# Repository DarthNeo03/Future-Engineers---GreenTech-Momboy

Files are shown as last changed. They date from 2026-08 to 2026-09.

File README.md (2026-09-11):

# GreenTech Momboy — WRO 2026 Future Engineers

Engineering documentation for our self-driving car: a 200 × 180 × 150 mm
printed chassis, one drive motor through a mechanical differential, Ackermann
steering, and a single USB camera that we turned into a distance sensor.

**Team GreenTech Momboy — Venezuela.** Two students, one coach, seventeen
chassis revisions and about four months of evenings.

| | |
|---|---|
| Category | Future Engineers |
| Season | WRO 2026 |
| Country | Venezuela |
| Vehicle | 200 mm × 180 mm × 150 mm — limit is 300 × 200 mm and 300 mm tall |
| Controllers | Raspberry Pi 5 (8 GB) + ESP32 |
| Perception | 1 USB camera, 1 gyroscope, 1 floor colour sensor |
| Software | Python 3.11 + OpenCV on the Pi, Arduino C++ on the ESP32 |
| Status | Both challenges running; parking manoeuvre in progress |

---

## The car

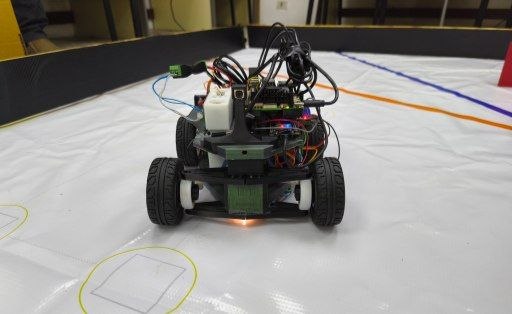
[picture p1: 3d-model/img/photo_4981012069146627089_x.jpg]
Front view


*Fig. 1 — Front view. Front axle, steering geometry at ride height, and the
status LED on the electronics deck.*

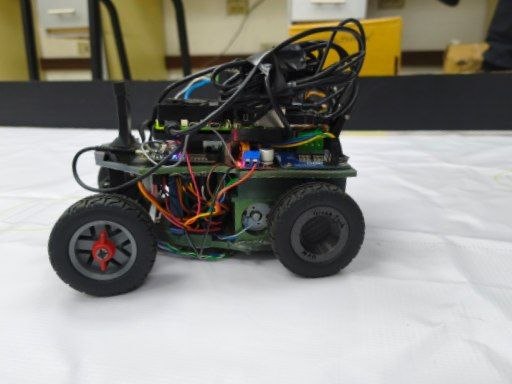
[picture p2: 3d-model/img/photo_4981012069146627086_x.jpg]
Side view


*Fig. 2 — Side profile. Wheelbase, motor/gearbox housing in the lower
chassis, and the wiring harness routed along the middle deck.*

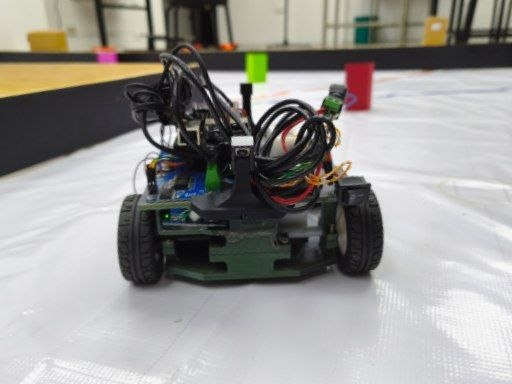
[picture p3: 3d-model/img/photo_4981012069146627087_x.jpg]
Rear view


*Fig. 3 — Rear view. Camera mast rising from the electronics deck, between
the rear wheels and the differential housing.*

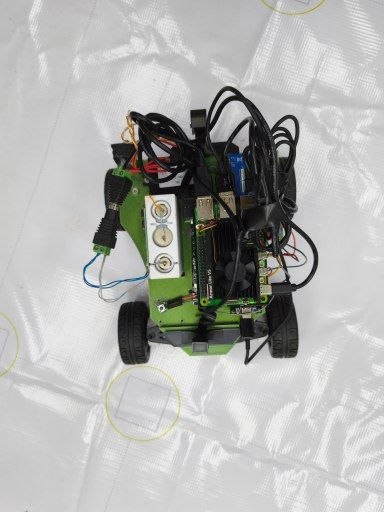
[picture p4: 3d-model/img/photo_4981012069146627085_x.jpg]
Top view


*Fig. 4 — Top view. Raspberry Pi 5 and wiring harness on the upper deck,
showing the wheel track and overall footprint.*

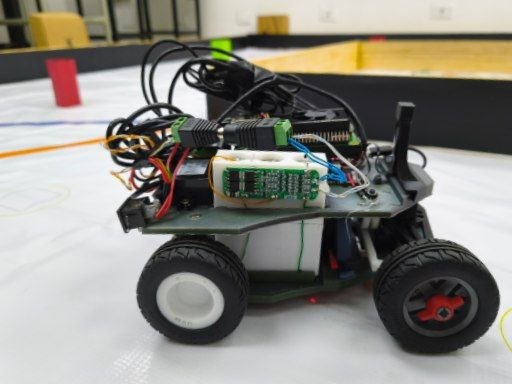
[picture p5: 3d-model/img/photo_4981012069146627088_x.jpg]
Front-quarter view


*Fig. 5 — Front, ¾ view. Front suspension links and the sensor mounts ahead
of the steering rack.*

---

## Contents

- [The car](#the-car)
- [Repository map](#repository-map)
- [The team](#the-team)
- [The vehicle](#the-vehicle-mobility-management)
- [Power and sensors](#power-and-sensors)
- [Software](#software-architecture)
- [Obstacle strategy](#obstacle-strategy)
- [Why we chose what we chose](#why-we-chose-what-we-chose)
- [Testing and reproducing our work](#testing-and-reproducing-our-work)
- [Rules compliance](#rules-compliance)

## Repository map

| Folder | What is in it |
|---|---|
| [`main/`](main/) | The car we race. Pilot program (Pi) + ESP32 firmware. Both challenges, selected by profile |
| [`fallback/`](fallback/) | The previous system, still runnable: reconizer (Pi) + the same firmware |
| [`schemes/`](schemes/) | Wiring diagram, system block diagram, pinout, power budget |
| [`3d-model/`](3d-model/) | Printed parts (STL) and the sliced projects with the settings we used |
| [`images/`](images/) | Team and vehicle photos, build photos, and the frames the car itself recorded |
| [`journal/`](journal/) | The engineering journal, the test logs, and the previous prototype |
| [`video/`](video/) | Links to the driving videos, one per challenge |

The two code folders are each complete and runnable on their own: `main/` is the
car we race today, `fallback/` is the system that came before it. Keeping both
means we can go back to a known-good program in the pits by changing which
`main.py` we launch, instead of reverse-engineering a git revert under pressure.

There is no separate folder per challenge. It is one program that runs both
rounds, and the round is chosen by which calibration profile is loaded — the
Obstacle Challenge simply switches obstacle handling on. Splitting it into two
copies would have meant fixing every bug twice.

Printed parts in [`3d-model/Documentación 3D/`](3d-model/Documentación%203D/)
are grouped by subassembly — full detail (screenshots, `.3mf` per part) in
[`3d-model/README.md`](3d-model/README.md#parts):

| Group | Function | Individual parts |
|---|---|---|
| [`A-Arm`](3d-model/Documentación%203D/A-Arm/) | Front suspension links | Lower A-Arm Left, Lower A-Arm Right, Upper A-Arm (2pcs) |
| [`Battery`](3d-model/Documentación%203D/Battery/) | Battery case and cell retention | Case (Lower/Upper 3S1P), Fittings (Cylinder ×4, Rectangle ×4) |
| [`Camera`](3d-model/Documentación%203D/Camera/) | Camera mast and mount | CameraMount, Camera Support Mount, LowerCameraMount, Pin |
| [`Chassis`](3d-model/Documentación%203D/Chassis/) | Structural core: motor mount, gear supports, steering rack housing, electronics deck | Lower, Middle, Upper Chassis, MotorChassis |
| [`Diferrential`](3d-model/Documentación%203D/Diferrential/) | Mechanical differential and drive gear train, rear axle | Crown Gear, Differential Case Cover, Left/Right Axle Support, MotorGear, PlanetGear (2pcs) + Axle, RearGearAndRing Left/Right |
| [`RaspberryPi5Mount`](3d-model/Documentación%203D/RaspberryPi5Mount/) | Raspberry Pi 5 mounting plate | RaspberryPi5Mount |
| [`Steering`](3d-model/Documentación%203D/Steering/) | Rack-and-pinion steering, Ackermann geometry | FrontRing (2pcs), FrontWasher, Servo Bracket, Steering Knuckle Left/Right, SteeringRack, SteeringServoGear, SteeringStop |

## The team

| | |
|---|---|
| **José Simón García Castellanos** | Obstacle challenge: pillar detection, avoidance geometry, the overtaking commitment |
| **Cristian José Rangel** | Open challenge: wall following, corner detection and counting, the CAD of the chassis |
| **Tutor / Coach** | **Msc. Edgardo Paolini** |

Both of us worked on every prototype, early and late. We split by *challenge*
rather than by layer on purpose: each of us owns a full vertical slice — camera
to wheels — for one round, which means either of us can debug an entire round
end to end without waiting for the other. The branches are shared, the debug
panel shows the same telemetry to both, and the merges are where we review each
other's work.

Our coach did not build or program the car — the rules are explicit about that,
and so are we. What our coach did was make sure a track existed to practise on,
ask "how do you know?" every single time we claimed something worked, and make
us stop and write things down at the exact moments we would rather have kept
hacking. Most of the failure analysis in this repository exists because somebody
kept asking that question.

## The vehicle (mobility management)

| | |
|---|---|
| Size | ≈ 200 mm long, 180 mm wide, 150 mm tall |
| Wheelbase | ≈ 150 mm |
| Wheels | Ø 65.2 mm |
| Drive | 1 DC motor, 500 rpm, 2:1 gearing, rear axle with a mechanical differential |
| Steering | Servo MG996R on a rack and pinion, Ackermann geometry, ≈26° at full lock |
| Top speed | ≈ 850 mm/s at full PWM; we cruise at about a fifth of that |
| Turning radius | ≈ 310 mm |
| Chassis | Printed PLA, seventeen revisions |
| Weight | 1150 g — limit is 1500 g |

### Speed and torque

The first motor we looked at ran at 1000 rpm. On a 3 × 3 m track with corners
every 3 metres, that is not fast, it is unusable: at that speed the car crosses
a floor line between two samples of the colour sensor, and the control loop
spends every corner recovering instead of driving. We went to a 500 rpm motor
with 2:1 gearing to the axle, which puts about 850 mm/s at the wheel with the
PWM at maximum — and in practice we run cruise at 55 out of 255, roughly
180 mm/s, because on this track reliability scores more points than speed.

Gearing down also gives us the torque to start smoothly from a stop, which
matters at the very beginning of the round: the parking bay start leaves no room
for a wheel-spinning launch.

### One motor, one steering actuator

The rules require exactly this, and they disqualify a differential-wheeled base.
So: one motor drives both rear wheels through a **mechanical differential**, and
one servo steers the front wheels through a rack and pinion with Ackermann
geometry. Nothing about direction is done by driving one side faster than the
other.

Ackermann steering shapes the software more than anything else on the car: the
rear wheel cuts inside the front one, so the car cannot return to the middle of
the lane the instant it has passed a pillar. That single geometric fact is where
the "overtaking commitment" in the obstacle code comes from.

### Why the chassis got smaller

We designed the first chassis around the components, and it was too long. The
compact chassis (revision XVII) came out of a list of things that were costing
us points on the track, and every item on that list was geometry:

- **The parking bay is 20 cm wide and 1.5 × the length of the robot.** A shorter
  car needs a shorter bay and can place itself less precisely. That is the
  cheapest improvement to the parking manoeuvre available, and it happens before
  any code runs.
- **The narrow track configuration is 600 mm wide.** With a 150 mm wheelbase and
  ~26° of lock we turn inside ~310 mm of radius, which fits.
- **The tail used to knock over the pillar we had just passed.** A shorter,
  narrower car sweeps a smaller area on the way out of an avoidance.
- **The camera stopped moving.** Every distance the software computes comes from
  two numbers, camera height (125 mm) and tilt (7.5°). On the old chassis the
  mast flexed, so those numbers were not constant, so no calibration held. On
  this one the mast is part of the structure.
- **Smaller parts print faster and fail less**, which decides how quickly you
  recover when something snaps two days before a test.

The full story, with dates, is in [`journal/engineering-journal.md`](journal/engineering-journal.md).

## Power and sensors

System block diagram

Full detail: [`schemes/`](schemes/) — [pinout](schemes/pinout.md),
[power budget](schemes/power-budget.md),
[wiring diagram](schemes/wiring-diagram.svg).

### Bill of materials

| Part | What it does | Where it connects |
|---|---|---|
| Raspberry Pi 5, 8 GB | Vision and decisions | USB camera, USB to the ESP32 |
| ESP32 | Hardware control and failsafe | Pi over USB serial (or GPIO 16/17) |
| Camera WN-L1812.K56R (IMX179) | The only sensor that sees the track | USB 2.0, MJPG, 30 fps |
| MPU-6050 | Yaw: heading on straights, closing the 90° turns | I2C 0x68 + INT on GPIO 18 |
| TCS34725 | Floor colour: the orange and blue corner lines | I2C 0x29 + INT on GPIO 19 |
| IBT-2 (BTS7960) | H-bridge for the drive motor | GPIO 25/26/27/33, PWM 20 kHz |
| Servo MG996R | Steering | GPIO 32, 50 Hz, 500–2400 µs |
| DC motor 500 rpm | Drive | Through 2:1 gearing to the rear axle |
| Battery pack | **TODO (team): chemistry, cells, capacity** | Main switch → H-bridge and regulator |

### Three sensors, and why not more

**The camera is the distance sensor.** With the lens at a known height and a
known tilt, every pixel on the floor maps to a millimetre distance. That gives
us a distance profile across the whole width of the image — a poor man's lidar —
instead of a single point. All the thresholds in the code (`turn below X mm`,
`stop below Y mm`) are physical distances, which is why the same calibration
works on the 1000 mm track and on the 600 mm one.

**We tried distance sensors and dropped them.** A single-point sensor cannot
tell a wall from a pillar, and it adds a rail, a cable and a failure mode for
information the camera already produces across the whole frame.

**The gyroscope earns its place** because an angle measured *from the car* is
useless for telling one wall from another — it changes with how crooked the car
is. The angle relative to the *track* is what matters, and converting between
the two needs exactly one number: how far the car has drifted from the heading
of the straight. That is the gyro. With it, one wall is enough to know whether
it is the wall of your lane or the far wall of the corner, even with the car
crossed at 45°.

**The colour sensor earns its place** because it is the only physical fact the
car gets. Everything else is inference from an image; the orange or blue line
passing under the car *happened*.

### Handling sensors that are not there

Both INT lines are optional: if they are not wired, the firmware detects it and
falls back to polling. On a competition weekend a broken jumper should cost
precision, not the round. The panel shows, sensor by sensor, what was detected.

That behaviour came from a real failure: the ESP32 used to probe the I2C bus
immediately after `Wire.begin()`, before the sensors woke up and while the motor
start-up pulled the rail down, and then declared both absent for the rest of the
run. Wait 250 ms, retry every 3 s, and give the humans a manual retry button.

### The start button, and stopping without the panel

The rules want the round to begin with a single action on a robot already
sitting on the track: no keyboard, no screen, no cable, nothing wireless. So
there is **one push button** on GPIO 13 — two wires and the internal pull-up,
no resistor — and it works like the start/stop of a stopwatch:

| Press it | With the car | What happens |
|---|---|---|
| once | stopped | arms and starts the round |
| again | running | disarms and stops |

Two details we argued about and are glad we got right:

- **It travels as a level, not as a counter.** A floor line is crossed in 40 ms
  and has to be latched and counted or it is lost; a finger holds a button for
  100–300 ms, which is four to twelve sensor frames. And a counter would store
  presses: a serial glitch with an undelivered press could start the car *by
  itself* on reconnect. With a level, what is lost is simply not executed —
  "nothing happens" is the good failure to have in front of a judge.
- **The emergency cut happens in the ESP32, not in the Pi.** With one button the
  ESP32 cannot know what a press means — except in the case that matters: if the
  car is *armed*, a press can only mean stop. Nobody presses to arm a car that is
  already moving. So it latches a local cut and the motor is dead on the next
  10 ms tick, without the round trip over serial and even if the Pi is hung
  shouting "forward".

A blue LED on GPIO 2 shows the state, so we can tell from outside the track
whether the car is armed, disarmed, or cut by the button.

There is also a daemon (`piloto.sh`) that runs the pilot with no web panel, so
in competition nothing on the car needs a network at all.

### Calibration, and the rule that shapes it

The rules do not let us calibrate after technical inspection, so everything is
calibrated before the car is handed in, and everything calibratable is saved as
a **profile** — up to twenty per challenge line, in three separate lines (Open
Challenge, obstacle avoidance, obstacles + parking) so that tuning one round can
never damage another round's working calibration.

Two habits that we learned the expensive way: freeze exposure and white balance
*before* calibrating colour, and never let the floor burn out — with white at
V=244 the floor lines drop to a saturation of 15–36 and no HSV threshold on
earth separates them from the floor.

## Software architecture

```
camera  →  geometry (px → mm)  →  wall profile ─┐
                                 lines ─────────┤→  navigation (state machine)  →  link  →  ESP32  →  motor + servo
                                 pillars ───────┘         ↑
                                                    race director (3 laps, stop in the finish section)
```

On the Pi (Python 3.11, OpenCV, NumPy — no ROS, no neural network):

| Module | Job |
|---|---|
| `geometria.py` | Pixels to millimetres on the floor; the horizon; the corridor the wheels will actually pass through |
| `muro.py` | Where the floor stops being floor; straight lines fitted in mm; inner and outer corners |
| `vision.py` | HSV masks and object detection: red and green pillars, orange and blue lines |
| `lineas.py` | Direction of the round, corner opening and closing, lap count |
| `navegacion.py` | The state machine: STRAIGHT, PRE-TURN, TURN 90, TWO-STAGE TURN, COLOUR TURN, ESCAPE |
| `obstaculos.py` | Which side to pass a pillar on, and committing to it |
| `carrera.py` | The race: three laps, twelve corners, stop inside the finish section, three-minute cap |
| `servidor.py` | The debug panel — bench and practice only |

On the ESP32 (Arduino C++, FreeRTOS, no external libraries): a receive task, a
sensor task woken by the sensors' own interrupts, a control task on a 10 ms
tick, a telemetry task, and a watchdog. No Wi-Fi is compiled in at all.

### The state machine, and the two bugs that shaped it

**Corners are entered on a physical fact.** The trigger we trust is the floor
line under the car, not the corridor closing in the image. A corner **opens**
with its first line and waits for the second to **close** it; the second can
never open a new one. With four corners in a row losing the blue line entirely,
the count still comes out at four.

**Once inside a corner, the turn is committed.** This is the fix for the corner
loop: when the inner wall ends it leaves a huge gap of white floor, and to any
free-space navigator that gap *is* the road. The car used to drive into it, see
another gap from its new position, and never come out — in one recorded capture
the corridor measured 1064 mm of clear road at precisely the moment the car had
to turn. So during the turn the camera cannot redirect the car; the turn ends on
the gyro angle or on a timeout, never because a tempting gap appeared. Safety
still overrides everything.

**The heading is re-anchored to the straight that exists.** The subtlest bug we
found: if the colour sensor missed a line, the car took the corner physically —
on white space alone — while the code still believed it was on the previous
straight, so the gyro pulled it back towards a straight that no longer existed
and into the wall. Now, if the car has held a corner-sized angle for long enough
*in the direction of the round*, it adopts the new straight.

**Reverse is special.** The only manoeuvres that reverse are the safety escape
and the two-stage turn — and the two-stage turn only runs on a corner confirmed
by a real pair of floor lines, because reversing in the middle of a straight
because the vision imagined a corner is how you hit whatever is behind you.

## Obstacle strategy

Red pillars are passed on their right, green on their left, and getting it wrong
ends the round. So the side is decided by the **colour** and is never
negotiable: only the distance is clipped to the free gap. If the gap is too
tight for a comfortable margin the car squeezes to the physical minimum (half a
car plus half a pillar); if not even that fits, it says so on screen and the
wall avoidance takes over.

Left and right are the *vehicle's*, so nothing needs flipping when the round
runs the other way. And because the cost of being wrong is the whole round, the
overlay draws a green arrow to the pass point and writes "red → pass on its
right", so we verify it with the car standing still.

Three failures worth reading, all fixed and all documented in
[`main/README.md`](main/README.md):

1. Steering saturating as the car closed on a pillar (96 % of lock at 600 mm,
   100 % at 400 mm) — fixed with a minimum look-ahead, a ceiling on what
   avoidance can ask for, and a slew-rate limit.
2. The rear wheel sweeping the pillar away once it left the camera's view —
   fixed with an overtaking commitment computed from real speed and car length.
3. A pillar against the inner wall driving the car into the corner — fixed by
   fading the pillar's authority as the corridor narrows, and by aiming at the
   middle of the gap when the gap is narrower than the car.

Pillars seen **behind** the floor lines belong to the next section and are
filtered out until the car enters the corner zone; reacting to them early drags
the car onto the inner corner exactly when it should be setting up to turn.

## Why we chose what we chose

| Decision | Alternative | Why |
|---|---|---|
| Raspberry Pi 5 + ESP32 | One controller doing everything | The vision loop used to stall the control loop. Now the control tick never misses, and if the Pi dies the ESP32 stops the car after 300 ms |
| ESP32 with no Wi-Fi compiled in | Wi-Fi for convenience | Two things that can give orders is one too many — and the rules forbid wireless while the vehicle runs |
| Classical computer vision (HSV + geometry) | A neural network | It runs at 30 fps on a CPU, it is deterministic, we can re-calibrate it in fifteen minutes at the venue, and when it fails we can point at the reason |
| Camera as the distance sensor | Lidar / time-of-flight sensors | Distance across the whole frame instead of one point, and one fewer thing to break. A single-point sensor cannot tell a wall from a pillar |
| Gyroscope kept | Camera only | Distinguishing "the wall of my lane" from "the far wall of the corner" needs the angle relative to the *track*, and only the gyro provides the conversion |
| Colour sensor kept | Detecting the corner lines with the camera only | The camera sees the line before it arrives; the sensor knows it *passed*. We use both, and the physical one is the one that counts corners |
| One motor + mechanical differential | Two motors, one per side | The rules disqualify a differential-wheeled base. Also, one motor cannot drift out of sync with itself |
| Profiles, everything tunable live | Recompiling to change a threshold | Nobody recompiles calmly at a competition |

## Testing and reproducing our work

```bash
git clone https://github.com/DarthNeo03/Future-Engineers---GreenTech-Momboy.git
cd Future-Engineers---GreenTech-Momboy/main/raspberry-pi

python3 -m venv .venv && source .venv/bin/activate
pip install -r requirements.txt      # opencv-python, numpy, pyserial

python3 tools/selftest.py            # 323 checks — no camera, no car, no ESP32
python3 main.py --simulado           # run the whole pilot on a laptop
python3 main.py --imagen ../../images/test-captures/frames/...   # replay a real frame
python3 main.py                      # the real thing: camera + ESP32 + panel
```

The ESP32 side: open `firmware/esp32/esp32_carro.ino` in the Arduino IDE (all
five files in the same folder) and upload — no external libraries. Upload new
firmware **before** running `main.py`.

Three things make this project reproducible, and they were worth more to us than
any single algorithm:

- **323 checks that run on any laptop.** Everything that can break hardware or
  count wrong lives in pure Python or pure C++ and is tested without the car.
  There is one car and two of us; whoever does not have it can still work.
- **The car records what it sees.** The frame sequences in
  [`images/test-captures/`](images/test-captures/) and the run logs in
  [`journal/test-logs/`](journal/test-logs/) are from real sessions, and any of
  them can be replayed offline. Every fix in September was accepted because a
  recorded run improved, not because the fix sounded right.
- **A synthetic scene in the self-test** reproduces the shiny-wall failure: the
  old wall-detection method fails on it and the new one does not, so the bug can
  never come back unnoticed.

## Rules compliance

| Requirement (WRO 2026 Future Engineers) | Us |
|---|---|
| Max 300 × 200 mm, 300 mm tall | 200 × 180 × 150 mm |
| Max 1500 g | 1150 g |
| Max two drive motors, connected to the axle through gearing | One motor, 2:1 gearing, mechanical differential |
| One steering actuator | MG996R on a rack and pinion |
| Differential-wheeled base disqualified | Ackermann steering; no independent side drive |
| No radio, Bluetooth or Wi-Fi while running | No Wi-Fi in the firmware; the Pi's panel and access point are shut down for the round |
| One switch, one start button | Main switch on the battery rail, and one push button on GPIO 13: press it once and the round starts, press it again and the car stops |
| Wired connections only between components | USB and jumper wires |
| No calibration after technical inspection | Everything is calibrated beforehand and saved as profiles |
| Repository public, and public for 12 months after the event | Public; will stay up |
| Three commits at the required deadlines | Our history runs from 7 May, with work committed continuously |
| README of at least 5000 characters | This one |
| Video of at least 30 s per challenge | [Open Challenge](https://youtu.be/Z215ovmq5Jg) (0:40) and [Obstacle Challenge](https://youtube.com/shorts/VIz5sVFtg74) (1:38) — also listed in [`video/video.md`](video/video.md) |
| The team builds and codes the robot, not the coach | Two students wrote every line and printed every part |

## License

See [`LICENSE`](LICENSE). The engineering notes inside
`main/raspberry-pi/README.md` and
`journal/prototypes/CONTEXTO-reconizer.md` are in Spanish, the language we work
in; everything a judge needs is in English here.

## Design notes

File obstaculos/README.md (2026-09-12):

# Sistema de control — Reto de Obstáculos

Pila completa y autocontenida para el **Desafío de Obstáculos** de WRO 2026
Future Engineers. Raspberry Pi 5 (visión y decisiones) + ESP32 (hardware y
failsafe), unidos por serial a 115200 8N1.

La **[bitácora](BITACORA.md)** cuenta cómo llegó a ser así: los nueve fallos
que aparecieron, cómo se aisló cada uno y qué queda pendiente —incluido lo que
puede romper hardware. Este README explica cómo funciona; la bitácora, por qué.

No hay nada de estacionamiento en este código. Los delimitadores magenta del
cajón sí aparecen, pero **como muro intocable**, nunca como objetivo: la regla
9.25.7 termina la ronda en el instante en que el vehículo los toca.

---

## Mapa de conexiones

| Función | Pin ESP32 | Detalle |
|---|---|---|
| Tracción RPWM | GPIO 25 | IBT-2 (BTS7960), PWM 20 kHz / 8 bits |
| Tracción LPWM | GPIO 26 | idem |
| Tracción R_EN | GPIO 27 | habilitación; en BAJO = puente en alta impedancia |
| Tracción L_EN | GPIO 33 | idem |
| Dirección | GPIO 32 | servo MG996R, 50 Hz, 500–2400 µs, 16 bits |
| I2C SDA | GPIO 21 | bus a 400 kHz |
| I2C SCL | GPIO 22 | |
| MPU-6050 | 0x68 | INT (data ready) → GPIO 18, push-pull, activo ALTO |
| TCS34725 | 0x29 | INT (umbral de claro) → GPIO 19, open-drain, activo BAJO |
| Botón de inicio | GPIO 13 | a GND, pull-up interno |
| LED de estado | GPIO 2 | azul de a bordo |
| Serial2 RX2 | GPIO 16 | ← TX de la Pi |
| Serial2 TX2 | GPIO 17 | → RX de la Pi |
| Cámara | — | WN-L1812.K56R (IMX179) por USB 2.0 a la Pi, MJPG 640×480 @30 |

Las dos patas INT son **opcionales**: el firmware detecta solo si están
cableadas y, si no, sigue por sondeo. Con ellas el rumbo se integra con el `dt`
real del sensor y los cruces de línea llevan marca de tiempo del ISR.

---

## Reparto de responsabilidades

```
Raspberry Pi 5                             ESP32
──────────────                             ─────
cámara → visión → geometría                tareaRx        valida CRC, publica
        ↓                                  tareaSensores  MPU + TCS por I2C
  carril  +  señales   (por separado)      tareaControl   100 Hz, rampas, HW
        ↓                                  tareaVigilante corta si algo calla
      mezcla → FSM → Orden
        ↓
   hilo TX a 50 Hz  ─────── serial ──────► failsafe a 300 ms
```

Regla de diseño: **la Pi piensa, el ESP32 obedece y desconfía.** Si la Pi se
cuelga, el ESP32 corta la tracción él solo a los 300 ms. Si la tarea de control
del ESP32 se cuelga, el vigilante baja los enables a los 200 ms.

El motor necesita **dos llaves**: el botón físico (`armadoLocal`, que vive en el
ESP32) y la bandera `F_ARMADO` de la Pi. Ninguna de las dos basta por sí sola.

---

## Estructura

```
firmware/esp32/esp32_obstaculos/     (la carpeta debe llamarse como el .ino:
  esp32_obstaculos.ino   pines, PWM, tareas FreeRTOS, failsafe   lo exige el IDE)
  protocolo.h            trama binaria  ← gemelo de src/protocolo.py
  seguridad.h            topes del servo, rampas, protección de inversión
  sensores_i2c.h         MPU-6050 y TCS34725 a registro
  lineas.h               clasificador naranja/azul del piso
  panel.h                botón antirrebote + patrones del LED

raspberry-pi/
  main.py                punto de entrada
  config/pista.json      todo lo ajustable
  src/protocolo.py       trama binaria  ← gemelo de protocolo.h
  src/enlace.py          serial: hilo RX + hilo TX a 50 Hz
  src/camara.py          captura MJPG en hilo, buffer de uno
  src/geometria.py       píxeles → milímetros sobre el suelo
  src/vision.py          segmentación HSV → escena en milímetros
  src/carril.py          mantenerse en la pista
  src/senales.py         rebasar los pilares por el lado que manda la regla
  src/vueltas.py         contar secciones y vueltas, y de qué lado se corre
  src/fsm.py             máquina de estados
  src/piloto.py          lazo principal
  src/panel.py           ventana de depuración (solo taller)
  tools/selftest.py      pruebas sin carro
```

---

## Puesta en marcha

**1. Firmware.** Arduino IDE con el core **ESP32 3.x** (la API `ledcAttach` /
`ledcWrite(pin, ...)` es de la 3.x; con la 2.x no compila). Abrir
`firmware/esp32/esp32_obstaculos/esp32_obstaculos.ino` y subir. No hace falta ninguna librería
externa: los dos sensores están escritos a registro sobre `Wire`.

**2. Pi.**

```bash
cd obstaculos/raspberry-pi && pip install -r requirements.txt
```

**3. Comprobar sin carro.**

```bash
python3 tools/selftest.py
```

**4. Rodar.**

```bash
python3 main.py
```

y pulsar el botón del carro cuando el juez diga «¡ya!».

En el taller: `--sin-motor` (pone el techo de PWM a 0, así ninguna rama del
código puede mover nada), `--ver` (ventana de depuración), `--puerto COM7`,
`--lineas` (monitor del sensor de color, empujando el carro a mano).

---

## Calibración, en el orden en que hay que hacerla

Cada paso supone que el anterior está bien. Saltarse el orden es la forma
habitual de perder una tarde persiguiendo un fallo que estaba dos pasos antes.

1. **Servo.** Con el carro levantado, comprobar que `centro` deja las ruedas
   rectas y que `izquierda`/`derecha` no hacen tope contra la cremallera. Los
   topes duros están en `seguridad.h` como constantes de compilación: el JSON
   solo puede estrechar ese rango, nunca ampliarlo.

2. **Geometría de la cámara.** El parámetro que de verdad importa para los
   pilares es **`fy_px`**: la distancia a una señal se deduce de su altura
   aparente, y eso solo depende de la focal. Resuélvelo poniendo un pilar a
   una distancia conocida.

   `inclinacion_deg` y `alto_cam_mm` son secundarios a propósito: solo afectan
   a la medida por base, que ahora únicamente corrobora. Un mástil torcido ya
   no hace desaparecer los pilares — antes sí, y por eso el carro los
   ignoraba. Si aun así quieres afinarlos, la ventana de `--ver` muestra las
   dos distancias juntas: cuando se separan mucho, vuelve a medir el mástil.

3. **Colores.** Con `--ver`, sobre el tapete de verdad y con la luz de verdad.
   Lo que importa no es que el pilar se vea entero: es que **nada más** se vea.

4. **`pwm_min_motor`.** Súbelo de 5 en 5 (arranca en 55) hasta que el carro
   arranque limpio desde parado sobre el tapete, y ni uno más. Es lo que evita
   que el motor zumbe sin moverse a bajo porcentaje.

5. **`mm_s_por_pct`.** Mandar 40 % durante 3 s en recta, medir la distancia,
   dividir. De este número dependen el odómetro y la duración del compromiso.

6. **`color_entrada_horario`.** Empujar el carro a mano por la pista en sentido
   horario y mirar qué color reporta el primer cruce. **No se adivina**: de
   esto depende que el sentido de la ronda se deduzca bien.

   De este único parámetro salen las dos respuestas: el color suelto da el
   sentido *provisional* en cuanto se pisa la primera línea, y el par
   ordenado (entrada + el otro color) lo *confirma* al completar la primera
   esquina. En `--ver`, la línea `sentido` dice cuál de las dos está mandando.

---

## Lo que este sistema no sabe hacer

Dicho antes de que lo descubra la pista:

- **No hay encoder en las ruedas.** El odómetro se integra del porcentaje de
  mando (`mm_s_por_pct`), con un error del 10–15 %. Basta para medir el tramo
  de recta hasta la meta, pero no serviría para navegar por estima. Por eso el
  detector de atasco mira **la imagen**, no la velocidad estimada: preguntarle
  al acelerador si el coche se mueve no sirve de nada cuando está clavado.
- **Un pilar cada vez.** Con dos pilares seguidos se resuelve el primero y el
  segundo se replantea después. Planificar los dos a la vez con una sola cámara
  sale peor de lo que parece. Lo que sí se hace es **verlo antes**: ver la
  sección siguiente de abajo.
- **El firmware no está compilado en este repositorio.** No hay compilador
  cruzado en la máquina donde se escribió: `protocolo.h`, `seguridad.h` y
  `lineas.h` son C++ puro a propósito y se pueden verificar con `g++` en un PC,
  pero el `.ino` hay que abrirlo en el IDE para confirmarlo.
- **Los rangos HSV del `pista.json` son un punto de partida**, no una
  calibración. Ninguna tabla de colores sobrevive a un pabellón nuevo.

---

## Qué pasa justo después de esquivar

Es el momento más delicado de la vuelta. El pilar ya no se ve —la cámara no
llega tan abajo— y el carro va apuntando hacia el lado por el que lo rebasa.

- **El seguidor de carril está callado a propósito.** Si opinara, tiraría del
  carro hacia el centro del carril y la rueda trasera barrería el pilar: con
  dirección Ackermann la cola corta por dentro.
- **Lo que se sostiene es el rumbo, no el volante.** Se congela el *yaw* del
  MPU del instante en que el pilar entró en zona ciega y un proporcional
  devuelve el carro a él. Un volante fijo no traza una recta, traza un arco:
  con el modelo Ackermann simplificado, congelarlo 0,8 s desviaba **537 mm**,
  más de medio carril, directo al muro.
- **Pero el compromiso no termina soltando el carro donde esté: lo devuelve
  alineado.** Pasada `salida_desde` (55 %) del compromiso el pilar ya quedó
  atrás, y el rumbo objetivo se lleva poco a poco del congelado al del pasillo
  libre que ve el carril. Sin esto, el carril recibía un carro cruzado y con el
  muro delante, que es de donde salía el volantazo siguiente.
- **Sin MPU se endereza, y rápido.** No hay rumbo que sostener, así que el
  volante se suelta en `soltar_sin_mpu_s` (0,35 s) de reloj y el resto del
  adelantamiento se hace recto. Antes se desvanecía a lo largo de *todo* el
  compromiso, o sea que se mantenía casi entero durante la primera mitad: eso
  es el arco, otra vez, y contra la pared. Aun así, revisa el I²C: recto es lo
  mejor que se puede hacer a ciegas, no es tan bueno como sostener el rumbo.
- **La guardia anti-muro sí sigue despierta** (`guardia_muro` en `carril.py`).
  No centra: se calla mientras haya sitio y solo empuja cuando la separación
  lateral baja de `guardia_muro_mm`. Su autoridad crece con el progreso del
  adelantamiento, porque al principio el pilar sigue al costado y al final ya
  quedó atrás.

### Y después del compromiso hay un estado propio: REINCORPORACION

Lo que sale de un rebase no es un carro en pista: es un carro descolocado
hacia un lado y apuntando al muro, así que su cámara ve el frente cerrado.
Devolverlo directamente a `PISTA` era el fallo que dejaba al carro girando
hacia el lado del esquive hasta clavarse en la pared, porque el seguidor de
carril leía ese frente cerrado como una esquina y hacía las dos cosas que no
tocaban a la vez: bajar el centrado al 25 % —el único término que aparta al
carro del muro— y empujar con `sesgo_curva` hacia el lado al que giran las
curvas de la ronda.

**Y va RECTA, no al centro.** Son cosas distintas, y confundirlas era la
desviación que seguía viéndose después de cada esquive: el seguidor de carril
no va recto, va al *centro*, así que a un carro que sale del rebase desplazado
le manda cruzar — y el carro hace una ese (se cruza, se pasa, vuelve). Aquí se
sostiene el **rumbo** con el yaw, igual que en el compromiso, y el rumbo bueno
ya lo dejó puesto el propio compromiso al reenfilar hacia el pasillo. Lo único
que se le suma es la guardia anti-muro: no centra, solo impide el golpe.
Recentrarse es cosa de la recta siguiente, con sitio y sin prisa. Sin MPU no
hay rumbo que sostener y manda el carril; se nota.

El piloto además le pasa al carril `tras_pilar=True`, y con eso:

| Qué se apaga | Por qué |
|---|---|
| el sesgo de curva | ese frente cerrado no es una esquina, es el muro al que se apunta |
| el aprendizaje del sentido | esos grados de rumbo no son de ninguna curva; si entraran en el promedio, el sentido "aprendido" sería el del último esquive |
| la rebaja del centrado | es lo único que saca al carro del muro |

Se sale a `PISTA` cuando el carro está **enfilado** y despegado del muro
(`reincorporado_deg`) o cuando se agota `reincorporacion_max_s`. Enfilado, no
centrado: exigir centrado mientras se va recto a propósito es pedir algo que
este estado no hace, y se saldría siempre por tiempo. Un pilar nuevo interrumpe el estado y manda a `SENAL`:
recolocarse no puede ser excusa para pasar de largo la señal siguiente.

Medido en el escenario de prueba (carro a 150 mm del muro derecho después de
rebasar por la derecha, ronda horaria): el volante pasa de **−12 %** —un
empujón simbólico, porque el sesgo de curva tiraba hacia el muro— a **−66 %**.

### Un muro de frente no es un muro al costado

Fallo de fondo que salió al montar un escenario de prueba con la geometría de
verdad, y que explica por qué la guardia anti-muro nunca salvaba al carro. La
separación lateral se medía sobre todos los sectores con muro, y un muro
**frontal** ocupa todos los rumbos: su sector a 4 grados del morro, a 700 mm,
da `700·sen(4°) = 49 mm`. O sea que con el carro perfectamente centrado en un
carril de 1000 mm y una esquina a 700, el código reportaba muros a 46 mm **a
los dos lados**. Y como la guardia empuja con la diferencia, los dos empujones
se cancelaban y daba **exactamente 0** justo cuando hacía falta.

Ahora solo cuenta como costado lo que está más cerca que el frente
(`frac_frente_lateral`). Lo que hay delante ya se mide aparte, en
`dist_frente_mm`.

---

## Quién manda en las esquinas: la línea del piso

La cámara solo sabe decir que **el frente se cerró**, y eso le pasa en una
esquina igual que cuando el carro quedó apuntando a un muro después de rebasar
un pilar. De ahí salían los dos síntomas: giraba antes de tiempo (recortando la
curva, porque ve el muro un metro antes de que la curva empiece) y giraba a
medias (porque el seguidor de carril renegocia el volante cada ciclo contra el
centrado, y en cuanto asoma hueco afloja).

La línea del piso no se presta a esa confusión: o se pisa o no, y cae donde la
curva empieza de verdad. Así que el reparto es:

| Quién | Qué aporta |
|---|---|
| la línea del piso (TCS) | **CUÁNDO**: la primera línea de la esquina abre la curva |
| la cámara | **QUE ESTÁ AHÍ**: el frente tiene que estar cerrado de verdad |
| el sentido de la ronda | **HACIA DÓNDE**: naranja = horario = todas a la derecha |

Entre esquina y esquina, el carro va **recto**. Con eso, `Estado.ESQUINA` hace
un giro **comprometido**: `dir_esquina` (100 %) sostenido hasta haber girado
`esquina_grados` (78°) de yaw, sin renegociar. Lo único que se le suma es la
guardia anti-muro, que no discute el giro — solo impide rozar.

**El giro va a tope, y «a tope» es el rango del servo, no el 100 %.** Con
Ackermann el radio lo fija el ángulo de las ruedas, así que «más cerrado» es
literalmente más volante — pero `dir_esquina: 100` ya pide *exactamente* los
topes de `servo.izquierda` / `servo.derecha`. Con 65/135 ese «máximo» eran
±35°, y no había forma de cerrar más la curva desde el software por mucho que
se tocaran las ganancias. Los topes duros de `seguridad.h` son 50 y 145, o sea
que sobraba margen: el JSON está ahora en **58/142** (±42°).

> **Compruébalo con el carro levantado antes de rodar.** Si la cremallera hace
> tope, el servo se queda empujando contra el mecanismo, calienta y se rompe.
> Si toca, sube `izquierda` y baja `derecha` de tres en tres hasta que no.

La velocidad va aparte y **no cierra la curva: la abre.** Un carro rápido
desliza hacia fuera y el radio real sale mayor que el geométrico. `vel_esquina`
está en 34 % porque se pidió más velocidad; si con eso el carro vuelve a salir
pegado al muro exterior, lo que hay que tocar es el rango del servo, no esto.

**Las cuatro redes**, cada una por un fallo concreto:

- **Una esquina, un giro.** Las dos líneas de una curva caen dentro de los
  mismos 1000 mm de sección. Sin `dist_entre_esquinas_mm` (1200), la segunda
  encadenaría otro giro de 90°, y 90 + 90 es la pared de enfrente.
- **La cámara confirma.** Si el TCS se pierde la línea de *entrada*, la de
  *salida* abre un par nuevo y dispararía un giro justo al salir de la curva.
  Al salir, el frente está despejado: `esquina_frente_max_mm` lo descarta.
  Al entrar en la curva el muro exterior queda a ~1000 mm, y el umbral está en
  1400 para dejar holgura; si en pista ves la línea pero el estado no pasa a
  `esquina`, éste es el primer número que hay que subir.
- **Un pilar manda sobre la curva.** Rebasar por el lado que toca vale 8 o 10
  puntos (1.6, 1.7) y hacerlo por el malo termina la ronda; trazar bien la
  esquina no vale ninguno. Con `esquina_cede_peso` la señal interrumpe el giro
  y la curva la termina el seguidor de carril.
- **Sin MPU se sale por tiempo.** El yaw es la única medida directa de «cuánto
  he girado». Sin él queda `esquina_max_s`, que depende de la velocidad y del
  agarre: funciona, pero es un motivo más para tener el I²C sano.

Si el TCS no está (`tcs_ok` falso) no hay nada que esperar y todo vuelve al
seguidor de carril de siempre, que es lo que se describe abajo.

---

## Cómo sabe hacia dónde girar

En una pista WRO **todas las curvas van hacia el mismo lado**: en sentido
horario todas a la derecha, en antihorario todas a la izquierda. O sea que
basta acertar una para saber las once restantes. El seguidor usa tres cosas,
en este orden:

1. **El rumbo del hueco.** Se parte el frente en 32 sectores, se mide a qué
   distancia aparece el primer sólido en cada uno, y se apunta al **centro del
   tramo contiguo libre más ancho**. Al centro, no al sector más profundo: en
   una recta media imagen empata en el máximo y quedarse con el primero
   sesgaba el volante a la izquierda en cada recta.

2. **La separación lateral a cada muro**, para centrarse. Cada sector con muro
   se convierte en un punto del suelo (`x = d·sen θ`, `y = d·cos θ`) y se mide
   cuánto hay de verdad a cada lado. Si solo se ve un muro —lo normal dentro de
   una curva— se sigue a distancia fija de él.

3. **El sentido de las curvas**, que el carro **aprende de la primera que
   toma** (promediando el rumbo del hueco mientras está en curva). Sirve para
   las esquinas de frente, donde el muro exterior tapa la salida y el hueco
   queda casi centrado: ahí es donde antes se iba recto contra la pared.

   Mientras no haya tomado ninguna curva, acepta como pista el sentido que
   deduce `vueltas.py` de las líneas del piso. Es solo una ayuda de arranque:
   el sentido aprendido sigue mandando sobre ella, porque no depende de ningún
   parámetro, y así un `color_entrada_horario` mal puesto no puede hacer girar
   al revés.

   **Este aprendizaje solo come datos limpios.** Con `tras_pilar` no se
   acumula nada: si los ciclos de después de un rebase entraran en el
   promedio, el sentido que se "aprendería" sería el del último esquive, y a
   partir de ahí el carro empujaría hacia ese lado en las once curvas
   restantes.

**Y el sesgo lleva tres candados**, todos por el mismo fallo de pista:

1. Nunca con un rebase en curso o recién terminado.
2. Nunca **hacia** un muro que ya está a menos de `guardia_muro_mm`. El sesgo
   existe para resolver un hueco indeciso, no para meter el morro en la pared.
3. **Con el TCS vivo, espera a la línea.** Quien dispara la curva es el piso;
   este sesgo se queda de red y solo habla si el frente baja de
   `sesgo_desde_mm` (520 mm), o sea si la línea no llegó. Sin él, el carro
   empezaba a girar a 820 mm y llegaba a la línea ya torcido: eso es recortar
   la curva.

En la ventana de `--ver`: `hueco a N deg`, `sesgo` y `curvas hacia ...` dicen
qué está pensando, y salen avisos de `TRAS PILAR` y `MURO ENCIMA` cuando el
sesgo está callado. Si `curvas hacia` sigue en `sin aprender` después de dos
curvas, sube `sesgo_curva` o baja `aprender_curva_deg`.

## De qué lado se corre esta ronda

El reglamento sortea el sentido antes de cada ronda (9.3) y prohíbe metérselo
al programa a mano (9.4, 9.9), así que hay que leerlo de la pista. Se lee dos
veces, y la segunda corrige a la primera:

| Cuándo | Cómo | Qué vale |
|---|---|---|
| primera línea pisada | su color, contra `color_entrada_horario` | **provisional** |
| primera esquina entera | el **orden** del par naranja/azul | **firme** |

El par es el que de verdad contesta. La primera línea solo acierta si es de
verdad la de entrada, y en pista el TCS se salta líneas —una línea de 20 mm a
1 m/s dura 20 ms—: cuando se salta la de entrada, la de salida se toma por la
primera y **el sentido sale invertido**. Un carro que cree que las curvas van
al otro lado se estampa en la primera esquina de frente, y el fallo no se
parece en nada a su causa. Con el par da igual cuál de las dos se vea primero
si se ven las dos, porque lo que se mira es el orden.

Tres cautelas, y las tres evitan contestar mal en vez de no contestar:

- **Una línea suelta no se empareja con la de la esquina de al lado.** Caduca
  por `ventana_par_mm` (1500 mm; la sección de curva mide 1000) y abre un par
  nuevo. Un par inventado es peor que ningún par: contesta, y al revés.
- **Si los dos colores suben en el mismo ciclo de la Pi, no forman par.** Los
  cruces llegan como contadores acumulados, no como eventos con marca de
  tiempo, así que ahí el orden no se sabe.
- **Una vez firme, el sentido no cambia.** En esta pista no hay media vuelta:
  un par al revés es un cruce mal leído. Se cuenta en `pares_incoherentes` y
  se sigue.

Si `--ver` avisa de que **las líneas y las curvas no dicen el mismo sentido**,
una de las dos fuentes está mal, y lo más probable es `color_entrada_horario`
al revés — el aprendizaje del carril no depende de ningún parámetro.

---

## Si dice que terminó la ronda nada más pulsar el botón

Mira el resumen que imprime. Si las vueltas no cuadran con `dist_m`, el
contador se desbocó, no es que haya corrido:

```
'vueltas': 63, 'secciones': 255, 'cruces': 255, 'dist_m': 0.3
```

255 es la saturación de un contador de 8 bits, y 63 vueltas en 0,3 m es
imposible. Las tres redes que lo impiden:

| Red | Qué hace |
|---|---|
| `max_cruces_por_ciclo` | entre dos ciclos de la Pi no caben más de 2-3 cruces reales; por encima se resincroniza en vez de contar. Un reinicio del contador del ESP32 (200 → 0) daba un delta de 56 por la resta de 8 bits |
| contar solo con la ronda en marcha | en `ESPERA` el carro lleva minutos quieto delante del juez, y todo lo que entre ahí es ruido |
| `min_dist_por_vuelta_mm` | tres vueltas no caben en tres metros; una vuelta real ronda los 8 m |

Los contadores se ponen a cero **en el flanco del botón**, no al arrancar el
programa. Hacerlo en `preparar()` abría una carrera: la Pi tomaba su línea base
antes de que el ESP32 llegara a aplicar el `CAL_CERO_LINEAS`.

Si ves `resync` subiendo en la telemetría durante la ronda, el enlace serial
está perdiendo tramas: revisa el cableado de `Serial2` antes que el contador.

---

## Si no abre la cámara

```bash
python3 main.py --listar-camaras
```

Dice qué `/dev/video*` existen y cuál está ocupado, leyendo `/proc` (no
necesita `fuser` ni `lsof`, que no vienen en Raspbian Lite).

| Lo que sale | Qué pasa |
|---|---|
| `Device '/dev/video0' is busy` | otra ejecución la tiene abierta → `pkill -f "python3 main.py"` |
| `No hay ningun /dev/video*` | no está enchufada o el kernel no la vio → `lsusb`, `dmesg \| tail` |
| abre pero no entrega imagen | es el nodo de **metadatos** de la UVC, no el de captura → `v4l2-ctl --list-devices` y `--camara N` |

Si el índice del JSON falla, el programa prueba solo los demás `/dev/videoN` y
avisa de cuál acabó usando. El orden de enumeración puede cambiar con un
reinicio, y quedarse sin correr por eso teniendo el resto listo sería absurdo —
pero conviene fijar el índice bueno en `pista.json` igualmente.

---

## Si el carro vuelve a ignorar los pilares

Mira **`descartes`** en la ventana de `--ver` (o en `piloto.ultimo`). Dice
exactamente qué filtro se está comiendo los contornos:

| Qué aparece | Qué significa | Qué tocar |
|---|---|---|
| `descartes` vacío y `pilares vistos: 0` | la máscara HSV no ve nada | rangos de `rojo` / `verde` en `pista.json` |
| `rojo:area` | los ve, pero muy pequeños | baja `area_min` |
| `rojo:horizonte` | caen por encima del horizonte | sube `margen_horizonte_px`, y remide `inclinacion_deg` |
| `rojo:forma` / `rojo:llenado` | la mancha no parece un pilar | afloja `aspecto_min/max`, `llenado_min` |
| `geometria_discrepa` alto | mástil torcido; **ya no descarta**, solo baja confianza | remide `inclinacion_deg` cuando puedas |
| detecta pilares pero `esquive_peso` sigue a 0 | la puerta de sección los está tapando | pon `usar_limite_seccion: false` |

---

## Si el carro gira sin sentido justo después de rebasar un pilar

Este era EL fallo: rebasaba bien y acto seguido seguía girando hacia el lado
del esquive hasta clavarse en la pared. Mira estas cuatro cosas de `--ver`, en
este orden, que es el orden en que se encadenaban las causas:

| Qué mirar | Qué significa si sale mal |
|---|---|
| `lateral izq`/`der` con una esquina de frente | si los dos bajan a la vez con el carro centrado, el muro frontal se está colando en la medida lateral: revisa `frac_frente_lateral` |
| el estado después del esquive | tiene que ser `reincorporacion`, no `pista` |
| `sesgo` durante esa reincorporación | tiene que ser `0`, y salir el aviso `TRAS PILAR` |
| `sentido` | si dice `(provisional)` después de la primera curva, el par de la esquina no se está completando: el TCS se está saltando una de las dos líneas |
| que aparezca `LINEA ...: empieza la curva` al llegar a cada esquina | si no aparece, el TCS no está viendo las líneas y el carro está girando solo por cámara — que es girar recortando |
| el estado al pisar la línea | tiene que ser `esquina`, con el volante en `dir_esquina` y sostenido |

Y si sale el aviso de que **las líneas y las curvas no dicen el mismo
sentido**, para y arregla `color_entrada_horario` antes de seguir rodando: el
carro está funcionando con dos respuestas contradictorias a la pregunta de
hacia dónde giran las curvas.

---

## Si el TCS no ve las líneas del piso

Desde que la curva la dispara la línea, esto deja de ser un problema de
contador y pasa a ser un problema de conducción: sin líneas, el carro gira solo
por cámara y vuelve a recortar las curvas.

### El hueco de 48 ms

Era un fallo de aritmética, no de sensor, y no se ve mirando el TCS: se ve
haciendo la cuenta. El chip integra durante `periodoMs()` y el firmware
preguntaba **cada** `periodoMs()`. Dos relojes a la misma frecuencia y sin
sincronizar derivan; y en cuanto derivan, la pregunta cae siempre un pelo
*antes* de que el dato exista. Como el hueco hasta la pregunta siguiente ya
estaba reservado, el periodo real pasaba a ser **el doble**. Una línea de 20 mm
a 1 m/s dura 20 ms: en un hueco de 48 ms cabe entera sin dejar rastro.

La solución no es afinar el periodo —dos relojes libres siempre acaban
derivando— sino dejar de programarlo:

| Antes | Ahora |
|---|---|
| integra 24 ms, pregunta cada 24 ms | integra **12 ms**, sondea cada **2 ms** y coge la muestra en cuanto el chip dice que vale |
| `leerColor()` devolvía `true` aunque siguiera integrando, y el clasificador comía la muestra anterior otra vez | `true` **solo** si `c/r/g/b` se acaban de actualizar |
| hacían falta **dos** lecturas seguidas para contar un cruce | la permanencia se cuenta en **milisegundos**: una lectura de 12 ms ya son 12 ms de luz recogida |
| `blanco` arrancaba en 1 y subía a 1/64 por muestra: ~10 s ciego al encender | la primera lectura se adopta entera |

La ganancia se queda en **x16** a propósito: los valores absolutos bajan con
`atime`, y la tentación es subirla, pero con 12 ms y x60 el tapete blanco
**satura** — y en cuanto satura, los ratios entre canales dejan de valer, que
es justo el discriminador. No hay que recalibrar nada a mano: el nivel de
blanco lo aprende el clasificador solo.

**Hay que volver a subir el firmware.** El `.ino`, `lineas.h`, `sensores_i2c.h`
y `protocolo.h` cambian todos.

### El claro no puede ser la puerta de entrada (y eso costó la naranja)

Segundo fallo, y explica el síntoma exacto —«la naranja no y la azul casi»—
mejor que cualquier umbral. El clasificador exigía que el piso **se
oscureciera** por debajo del 78 % del blanco para admitir que había línea.
Suena razonable y es una trampa para los colores claros: la naranja es
CMYK(0,60,100,0), refleja el rojo y el verde casi como el tapete, y su canal
claro se queda rondando ese umbral — un día entra y otro no, según la luz de
la sala y según dónde quedara el blanco aprendido. La azul, que es oscura,
pasaba esa puerta siempre.

El oscurecimiento nunca fue la prueba de que hay una línea: la prueba es el
**color**. El tapete blanco da `r − b ≈ 0` haga la luz que haga, así que el
discriminante ya separa tapete de línea él solo.

| | Antes | Ahora |
|---|---|---|
| quién decide | el claro **y** el color | el **color** |
| histéresis | sobre el claro (78 / 88 %) | sobre \|sep\| (45 entra / 25 sale) |
| papel del claro | puerta de entrada | **suelo** (12 %), solo para descartar el muro negro, donde las cuentas son ruido y su cociente puede dar cualquier cosa |

También sube `PCT_UMBRAL_INT` de 55 a 90: con 55 la interrupción del TCS no
saltaba nunca para la naranja. Desde que se sondea a 500 Hz no se depende de
ella, pero un umbral que ignora medio juego de líneas es mentira en el código.

### Y si aun así no las ve: `--lineas`

```bash
python3 main.py --lineas
```

Sin cámara y sin motor. Se empuja el carro **a mano** sobre cada línea y al
salir (Ctrl-C) imprime el `sep` máximo (en valor absoluto) que llegó a ver
sobre cada color y
cuántos cruces llegó a contar. Con eso, «no ve las líneas» deja de ser una
queja y pasa a ser una de tres cosas, cada una con un arreglo distinto:

| Lo que dice el resumen | Qué pasa |
|---|---|
| `sep` máximo (en valor absoluto) por debajo de 45 | **el color no llega**. Ningún umbral arregla una señal que no está: baja el sensor, limpia la lente, comprueba que el LED blanco enciende |
| `sep` de sobra pero 0 cruces contados | la línea se cruza demasiado rápido para los `ms_minimo`. Cruzarla más despacio a mano lo confirma |
| `firmware viejo` | el ESP32 no manda `blanco`/`separacion`: vuelve a subirlo |

### Y en marcha, en `--ver`

La misma información sin parar el carro:

```
TCS: claro 640/900 = 71%   sep -146 -> azul   (hace falta |sep|>=45)
```

| Lo que sale | Qué falla | Qué mirar |
|---|---|---|
| `sep` se queda corto sobre la línea | el color no llega | altura del sensor, lente sucia, LED apagado |
| `sep` con el signo cambiado | naranja y azul intercambiados | revisa `color_entrada_horario`, que es lo que ata color y sentido |
| el `%` no baja nada al pasar la línea | el sensor no está mirando la línea | está desalineado, o va tan alto que promedia línea y tapete |
| `TCS: ausente` | el I²C no responde | cableado; las esquinas irán solo por cámara |
| `firmware viejo` | el ESP32 no manda `blanco`/`separacion` | vuelve a subir el firmware |

La trama de sensores creció de 12 a 16 bytes para poder decir esto, pero los
cuatro nuevos son **opcionales**: una Pi actualizada con un ESP32 sin
reflashear sigue funcionando, porque actualizar la Pi es copiar ficheros y
reflashear pide cable — el orden en que pasa en la práctica.

---

## Hasta dónde se ven los pilares

`activar_desde_mm` no manda aquí. El tope real lo pone **`area_min`**, y los
dos se habían quedado descoordinados. Un pilar de 50 × 100 mm a distancia *d*
ocupa del orden de `8.5e8 / d²` píxeles:

| distancia | área aparente |
|---|---|
| 1,6 m | 330 px |
| 2,4 m | 147 px |
| 3,0 m | 94 px |

Con `area_min: 320` el carro era **ciego más allá de 1,6 m** por mucho que el
JSON dijera otra cosa — medido sobre pilares sintéticos: detectaba a 1600 y no
a 2000. Con `area_min: 140` llega a ~2,8 m, y `activar_desde_mm` sube a 2400
para acompañarlo. Bajar más el área empieza a colar manchas: los filtros de
forma pierden sentido cuando la caja mide diez píxeles.

**Para qué sirve verlos antes.** Para tener la trayectoria decidida *antes* de
terminar de rebasar el anterior, en vez de descubrir el siguiente cuando ya no
queda sitio para colocarse. Dos números lo acompañan, y los dos existen porque
ver más lejos tiene efectos colaterales:

- **`senal_desde_peso` (0,30).** Entrar en `SENAL` es entrar en `vel_senal`.
  Con el umbral viejo (0,15) y los pilares vistos a 2,4 m, el carro se pasaba
  media recta frenado sin necesidad.
- **`reincorporacion_cede_peso` (0,45).** Un pilar lejano ya no interrumpe la
  reincorporación. Si lo hiciera, volvería a mandar el seguidor de carril —que
  centra— y con él la ese que ese estado existe para quitar.

---

## Si pasa más cerca de un color que del otro

El punto de paso es **simétrico en el código**: `lat_mm ± (25 + semiancho +
margen)`, con los mismos números para rojo y verde. Así que si en pista pasa
más cerca de uno, la asimetría no está en la geometría del esquive. Los dos
sospechosos, en orden de probabilidad:

1. **La máscara de ese color recorta el pilar.** La distancia primaria sale de
   la **altura aparente** (`dist_alto_mm`), así que un pilar recortado se ve
   más bajo, se reporta más lejos y el esquive arranca tarde. Con `--ver`,
   pon los dos colores a la misma distancia conocida y compara: si el verde
   dice 900 y el rojo 700 con los dos a 700, el problema es el rango HSV del
   verde, no el control.
2. **El carro llegaba mal colocado.** Si venía recortando la curva anterior,
   entra a la recta descentrado y el esquive parte con menos sitio del que
   debería. Esto es lo que arregla el giro por línea de arriba, así que vale
   la pena volver a medirlo después de probarlo.

Mientras tanto, `margen_verde_mm` / `margen_rojo_mm` compran despeje en el
color que lo necesite sin tocar el otro (hoy: verde 100, rojo 70). Es una
compensación, no un arreglo: si el verde se está midiendo mal, también se está
midiendo mal la distancia a la que arranca el compromiso. En `--ver`,
`margen pedido` dice cuánto se está pidiendo para el pilar que se está
atendiendo.

---

## Reglas del juego que están metidas en el código

Con la cita al lado, para que se puedan comprobar contra el reglamento:

| Regla | Dónde vive |
|---|---|
| 9.19 rojo por su derecha, verde por su izquierda | `senales.py` → `LADO_OBLIGADO` |
| 9.11 / 9.13 estado de espera y un solo botón | `fsm.py` → `Estado.ESPERA`, `panel.h` |
| 9.9 nada de calibrar a mano en el vehículo | `sensores_i2c.h`: el sesgo del giro se mide solo al encender |
| 9.25.7 tocar un delimitador termina la ronda | `carril.py` → `margen_magenta` |
| Apéndice A.5 hay margen para corregir el lado | `fsm.py` → `Estado.CORRECCION` |
| 9.23 volver a la sección de arranque y parar | `vueltas.py` → `evaluar_parada` |
| 9.3 / 9.4 el sentido se sortea y no se configura | `vueltas.py` → `_emparejar` (par ordenado de la esquina) |
| 13.9 las líneas marcan dónde empieza la curva | `fsm.py` → `Estado.ESQUINA` |
| 13.1 pilar de 50 × 50 × 100 mm | `senales.py`, `geometria.py` |
| 13.9 líneas naranja y azul de 20 mm | `lineas.h` |

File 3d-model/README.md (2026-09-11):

# 3D model

Every structural part of the car is printed. The chassis is not a box with
things screwed onto it: the motor mount, the gear supports, the steering rack
housing, the camera mast and the electronics deck are features of the same
model, which is the only way we got the car down to the size it is now.

```
3d-model/
├── stl/                    parts as printed
├── print-projects/         sliced projects (.3mf) with the settings we actually used
├── Documentación 3D/       one folder per part, grouped by function/subassembly
│   ├── A-Arm/
│   ├── Battery/
│   ├── Camera/
│   ├── Chassis/
│   ├── Diferrential/
│   ├── RaspberryPi5Mount/
│   └── Steering/
├── img/                    photos of the assembled car
└── README.md
```

## The car

Front view

*Fig. 1 — Front view. Front axle, steering geometry at ride height, and the
status LED on the electronics deck.*

Side view

*Fig. 2 — Side profile. Wheelbase, motor/gearbox housing in the lower
chassis, and the wiring harness routed along the middle deck.*

Rear view

*Fig. 3 — Rear view. Camera mast rising from the electronics deck, between
the rear wheels and the differential housing.*

Top view

*Fig. 4 — Top view. Raspberry Pi 5 and wiring harness on the upper deck,
showing the wheel track and overall footprint.*

Front-quarter view

*Fig. 5 — Front, ¾ view. Front suspension links and the sensor mounts ahead
of the steering rack.*

## Current design

**WRO CAR XVII** — the seventeenth iteration of the chassis, and the one the car
runs today.

| | |
|---|---|
| Overall size | ≈ 200 mm long × 180 mm wide × 150 mm tall |
| Rules limit | 300 × 200 mm footprint, 300 mm height, 1500 g |
| Wheelbase | ≈ 150 mm |
| Wheel diameter | 65.2 mm |
| Drive | one DC motor → 2:1 gearing → rear axle with a mechanical differential |
| Steering | MG996R on a rack and pinion, Ackermann geometry, ≈26° at full lock |
| Camera | 125 mm above the floor, tilted 7.5° down |
| Material | PLA |
| Weight | 1150 g (limit is 1500 g) |

## Parts

Every printed part lives in its own folder under
[`Documentación 3D/`](Documentación%203D/) — a `.3mf` (the sliced project,
ready to print) plus a reference screenshot. Folders are grouped by
subassembly, i.e. the parts that mount together or share a function:

| Group | Function | Individual parts |
|---|---|---|
| [`A-Arm/`](Documentación%203D/A-Arm/) | Front suspension links | `Lower A-Arm Left`, `Lower A-Arm Right`, `Upper A-Arm (2pcs)` |
| [`Battery/Case/`](Documentación%203D/Battery/Case/) | 3S1P battery enclosure | `Lower Case 3S1P Battery`, `Upper Case 3S1P Battery` |
| [`Battery/Fittings/`](Documentación%203D/Battery/Fittings/) | Cell retention inside the case | `Cylinder (4 parts)`, `Rectangle (4 parts)` |
| [`Camera/`](Documentación%203D/Camera/) | Camera mast and mount — the fixed geometry (125 mm height, 7.5° tilt) the vision pipeline relies on | `CameraMount`, `Camera Support Mount 82.5g`, `LowerCameraMount`, `Pin` |
| [`Chassis/`](Documentación%203D/Chassis/) | Structural core: motor mount, gear supports, steering rack housing, electronics deck | `Lower Chassis`, `Middle Chassis`, `MotorChassis`, `Upper Chassis` |
| [`Diferrential/`](Documentación%203D/Diferrential/) | Mechanical differential and drive gear train, rear axle | `Crown Gear 48D Train Type`, `Differential Case Cover`, `Left Axle Support`, `Right Axle Support`, `MotorGear_TrainType`, `PlanetGear (2pcs)`, `PlanetGearAxle`, `RearGearAndRingLeft`, `RearGearAndRingRight` (`GearRight`, `RearRingRight`, `RingGearCoupling`) |
| [`RaspberryPi5Mount/`](Documentación%203D/RaspberryPi5Mount/) | Raspberry Pi 5 mounting plate | `RaspberryPi5Mount` |
| [`Steering/`](Documentación%203D/Steering/) | Rack-and-pinion steering, Ackermann geometry | `FrontRing (2pcs)`, `FrontWasher`, `Servo Bracket`, `Steering Knuckle Left`, `Steering Knuckle Right`, `SteeringRack`, `SteeringServoGear`, `SteeringStop` |

## Why it got smaller instead of prettier

The first chassis was built to hold the parts. This one is built to fit the
track, and every millimetre we removed bought something specific:

- **The parking bay is 20 cm wide and 1.5 × the car's length.** A longer car
  needs a longer bay and has to hit it more precisely. Shortening the car is the
  cheapest possible improvement to the parking manoeuvre — it happens before any
  code runs.
- **Turning circle.** With a 150 mm wheelbase and ~26° of lock the car turns
  inside roughly 310 mm of radius. That is what lets it take a corner inside the
  narrow (600 mm) track configuration without a three-point turn.
- **The tail sweeps less.** With Ackermann steering the rear wheel cuts inside
  the front one. A shorter, narrower car sweeps a smaller area, and that is
  exactly the area that used to knock over the pillar we had just passed.
- **Weight and the print queue.** Smaller parts print faster and fail less. When
  a part broke two days before a test we could reprint it the same afternoon
  instead of losing the week.
- **Everything the camera needs is fixed by geometry.** Camera height and tilt
  are model dimensions, not adjustments — the software converts pixels to
  millimetres from those two numbers, so a chassis that holds the camera rigidly
  at 125 mm and 7.5° is worth more than any amount of calibration.

## Reprinting it

The `.3mf` projects carry the settings we used: 0.4 mm nozzle, 0.2 mm layers,
PLA. Print the base flat with no supports; the gear supports and the steering
parts want more perimeters than infill — they take load, and infill does not
carry it.

> **TODO (team):** export the parts of **WRO CAR XVII Final** to `stl/` and to
> STEP, and replace the older exports currently in this folder (they are from
> the June–July iterations). The Fusion source file is ~200 MB, well over
> GitHub's 100 MB per-file limit, so it does not belong in the repository: put a
> Fusion shared link here instead, and keep STL + STEP + 3MF as the files people
> can actually use.

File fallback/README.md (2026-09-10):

# fallback — the previous system, kept runnable

This folder is **reconizer**, the system we drove before the current pilot in
[`../main/`](../main/). It is here on purpose, and it is not
decoration — it still starts, still drives, and it is what we fall back to if
something goes badly wrong with the new program during a practice session.

```
fallback/
├── raspberry-pi/      reconizer: the earlier pilot (Python + OpenCV)
│   ├── main.py        entry point
│   ├── src/           vision, navigation, obstacles, laps, link
│   ├── config/        colors.json and robot.json
│   └── tools/         calibrator, desktop panel, self-tests
└── firmware/esp32/    the SAME firmware as main/ (see below)
```

## Running it

```bash
cd raspberry-pi
pip install -r requirements.txt
python3 main.py --vmax 70
```

Switching between the two systems is just which `main.py` you launch. That was
the whole reason for splitting the repository by branch instead of by round.

## The firmware is shared — read this before flashing

`fallback/firmware/esp32/` and `main/firmware/esp32/` hold the **same**
firmware, the one with the physical button and the status LED. One car, one
microcontroller, one binary to flash: keeping two firmwares and remembering
which one is on the ESP32 today is exactly the kind of mistake that costs a
round.

What that means in practice:

- **The button works here too.** The arm/disarm button on GPIO 13 and the cut it
  latches live inside the ESP32, so with this firmware the physical button stops
  the car even though reconizer's Python knows nothing about it.
- **The Python side of the button is not ported.** `botones.py` and the protocol
  changes that read the button bits exist only in `main/`. Reconizer is
  code we no longer develop, and writing an untested port of it into a program
  we do not race would be worse than saying this plainly.
- **The link still works** because the command frame did not change: same sync
  bytes, same CRC, same six-byte command. The newer firmware sends a sensor frame
  (yaw, floor colour, button) that reconizer's older protocol never asked for and
  simply does not read.

> **Check on the bench, not on the track:** wheels in the air,
> `python3 main.py --vmax 70`, confirm the car responds to the panel, then press
> the button with the car armed and confirm the motor cuts. Do that once after
> flashing and this whole section stops being a worry.

## What it taught us

Most of the failure list in [`../journal/engineering-journal.md`](../journal/engineering-journal.md)
was learned on this program: the wall measured as "the lowest black pixel",
which fails the moment a wall shines; the vote accumulator that saturated in one
second and always answered "clockwise"; the 180° turn measured with a short
angular difference, which wraps and never finishes.

Its handover document — the full list of mistakes we had already made by August,
written the day they happened — is at
[`../journal/prototypes/CONTEXTO-reconizer.md`](../journal/prototypes/CONTEXTO-reconizer.md).
It is in Spanish, our working language.

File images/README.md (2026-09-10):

# Images

| Folder | What goes in it |
|---|---|
| `team/` | Photos of the team (one serious, one not so serious) |
| `vehicle/` | The car from every side, from the top and from the bottom — required |
| `build/` | Build and workshop photos: printed parts, wiring, the car on the track |
| `test-captures/` | Frames the car itself saved during test runs, and the diagnostics we drew on them |
| `open.gif` | The car running the Open Challenge |

`test-captures/` is not decoration. Those sequences are the evidence behind
half the decisions in the journal: the shiny-wall failure, the corridor that
measured 1064 mm of clear road exactly where the car had to turn, the blue line
the colour sensor kept missing. Anyone can replay them with
`main/raspberry-pi/main.py --imagen <file>` and see what the car saw.

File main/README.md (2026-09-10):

# main — the car we race

This is the current system: the program that races, kept in `main/` so there is
never a doubt about which of the two is which (the one before it lives in
[`../fallback/`](../fallback/)).
It runs **both** rounds: the Open Challenge and the Obstacle Challenge are the
same program with a different calibration profile, not two codebases.

```
main/
├── raspberry-pi/      the pilot program (Python 3.11 + OpenCV)
│   ├── main.py        entry point
│   ├── piloto.sh      daemon: runs it with no web panel (for competition)
│   ├── src/           vision, geometry, walls, lines, navigation, obstacles, button, link
│   ├── config/        params.json and colors.json — profiles, three lines of them
│   ├── tools/         selftest.py — 323 checks, no hardware needed
│   └── README.md      the deep technical notes (Spanish, our working language)
└── firmware/esp32/    hardware controller: motor, servo, gyro, colour, button, failsafe
```

## Running it

```bash
cd raspberry-pi
python3 -m venv .venv && source .venv/bin/activate
pip install -r requirements.txt

python3 tools/selftest.py        # 323 checks, no camera, no car
python3 main.py                  # camera + ESP32 + web panel
python3 main.py --simulado       # on a laptop, without the ESP32
python3 main.py --imagen foto.jpg  # on a still, without a camera
python3 main.py --vmax 70        # PWM ceiling — always the first run of the day
```

ESP32: open `firmware/esp32/esp32_carro.ino` in the Arduino IDE (all files in
the same folder) and upload. No external libraries. **Upload the firmware before
running `main.py`** — if the protocol changed, old firmware just sits in
failsafe.

Then pick the profile line for the round you are practising: **Open Challenge**,
**Avoid obstacles**, or **Obstacles + parking**. They are stored separately, so
tuning one round can never damage another round's working calibration.

## Starting a round

One button on GPIO 13 — press to arm and start, press again to disarm and stop.
The blue LED on GPIO 2 tells you the state from across the track. In
competition, run it through `piloto.sh` so there is no web panel and no network
on the car at all.

## Open Challenge — three laps of an empty track

1. **The direction is worked out by the car.** Nothing may be fed to the robot
   before the start, so the direction comes from the first floor line it crosses
   — orange first is clockwise, blue first is counter-clockwise — with the camera
   as a second opinion and the side of the first turn as a third.
2. **It stays in the lane** by comparing free space left and right in
   millimetres, not pixels, with the gyro holding the heading on the straights.
3. **The corner is three moves:** brake and let the rear wheels clear the inner
   edge, turn 90° closed by the gyro, then straight again. The trigger we trust
   is the floor line, because it is a physical fact and not an inference.
4. **It counts corners, not laps.** A corner opens with its first line and waits
   for the other one to close it; four corners make a lap. If a line is missed,
   the completed 90° turn counts it instead — once, either way.
5. **It stops by itself** after corner twelve, driving on just long enough to sit
   entirely inside the finish section, which is where the bonus is.

### The two failures that cost us the most

**The shiny wall.** The first version looked for the lowest black pixel in each
column. The moment a wall caught the light it stopped being black, the contact
line jumped to the chairs behind the track, and the car believed the road was
clear. The fix was to stop asking "where is the black?" and start asking "where
does the floor stop being floor?", cutting everything above the geometric
horizon first.

**The corner loop.** When the inner wall ends it leaves an enormous gap of white
floor, and to any free-space navigator that gap *is* the road: the car drove into
it, saw another gap from its new position, and never came out. In one recorded
capture the corridor measured 1064 mm of clear road at exactly the moment the car
had to turn. No threshold fixes that. The answer was the floor line plus a
commitment: once inside a corner, the 90° turn runs to completion and the camera
cannot redirect it.

## Obstacle Challenge — the same laps, with traffic signs

Red pillars are passed on their right, green on their left, and passing one on
the wrong side ends the round. So the side comes from the **colour** and is never
negotiable; only the distance is clipped to the free gap. If the gap is too tight
for a comfortable margin the car squeezes to the physical minimum (half a car
plus half a pillar); if not even that fits, it says so on screen and wall
avoidance takes over.

Left and right are the *vehicle's*, so nothing needs flipping when the round runs
the other way. And because the cost of being wrong is the whole round, the
overlay draws a green arrow to the pass point and writes "red → pass on its
right", so we check it with the car standing still, before the round.

Three failures worth reading:

1. **Steering saturated as the car closed in** — the angle to the pass point was
   computed from the distance to the pillar, so the same lateral offset demanded
   more angle the closer it got: 96 % of lock at 600 mm, 100 % at 400 mm. Fixed
   with a minimum look-ahead, a ceiling of 55 % on what avoidance may ask for,
   and a slew-rate limit.
2. **The rear wheel swept the pillar away.** Up close the pillar leaves the
   camera's view, the avoidance vanished, lane-centring pulled the car back to
   the middle, and with Ackermann steering the tail cuts inside. Now there is an
   overtaking commitment: from the moment the pillar disappears, the car holds
   straight for as long as it needs to clear it with its whole length.
3. **A pillar against the inner wall drove the car into the corner.** The pillar
   could take 100 % of the command exactly when the wall was the real problem.
   Now its authority fades as the corridor narrows, and if the gap is narrower
   than the car, the car aims at the middle of the gap instead of picking a side.

One filter that is easy to miss: **pillars seen behind the floor lines belong to
the next section** and are ignored until the car enters the corner zone. Reacting
to them early drags the car onto the inner corner exactly when it should be
setting up to turn.

### Parking — the open item

The bay is 20 cm wide and 1.5 × the length of the robot, in the starting section.
The short chassis pays off twice here: a shorter car needs a shorter bay and
turns in a tighter circle to reach it.

> **Status:** the rear-camera slot is reserved (`camara.indice_trasera`) and the
> "Obstacles + parking" profile line exists, but the manoeuvre itself is still
> being written.

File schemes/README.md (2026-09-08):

# Electronics — how the car is wired and why

Two controllers, one job each. The Raspberry Pi 5 looks and decides; the ESP32
moves and protects. Everything between them is a serial cable and a binary
frame with a CRC.

- [`pinout.md`](pinout.md) — every pin, taken from the firmware we flash
- [`power-budget.md`](power-budget.md) — rails and current draw
- [`system-block-diagram.svg`](system-block-diagram.svg) — the picture below, printable
- [`wiring-diagram.svg`](wiring-diagram.svg) — connector-level wiring

## System block diagram

```mermaid
flowchart LR
    CAM["USB camera<br/>WN-L1812.K56R (IMX179)<br/>MJPG 30 fps"] -->|USB 2.0| PI

    subgraph PI_G["Raspberry Pi 5 (8 GB) — perception + decisions"]
        PI["OpenCV + NumPy (Python 3.11)<br/>wall profile, lines, pillars<br/>state machine, race director<br/>web panel (bench only)"]
    end

    PI <-->|"USB serial 115200<br/>binary frames + CRC"| ESP

    subgraph ESP_G["ESP32 — hardware controller + failsafe"]
        ESP["FreeRTOS: rx / sensors / control<br/>/ telemetry / watchdog<br/>ramps, servo limits, 300 ms failsafe"]
    end

    ESP -->|"GPIO 25/26/27/33<br/>PWM 20 kHz"| DRV["IBT-2 (BTS7960)<br/>H-bridge"]
    DRV -->|"M+ / M-"| MOT["DC motor 500 rpm<br/>2:1 gearing<br/>wheel Ø65.2 mm"]
    ESP -->|"GPIO 32<br/>50 Hz, 500-2400 us"| SRV["Servo MG996R<br/>rack and pinion<br/>Ackermann steering"]

    IMU["MPU-6050<br/>yaw"] <-->|"I2C 0x68, 400 kHz"| ESP
    TCS["TCS34725<br/>floor colour"] <-->|"I2C 0x29"| ESP
    IMU -->|"INT GPIO 18<br/>data ready"| ESP
    TCS -->|"INT GPIO 19<br/>line edge"| ESP
```

## Why it is split this way

**One brain that sees, one that obeys.** The camera work needs an SBC; the motor
needs a hard 10 ms tick. Putting both on the same processor meant the vision
loop stalling the motor loop, and we saw exactly that on the first prototype.
With the ESP32 in the middle the control tick never misses, and — the part that
actually matters in competition — **if the Pi crashes or the USB is yanked, the
ESP32 stops the car by itself after 300 ms.**

**The sensors hang off the ESP32, not off the Pi.** The MPU-6050 and the
TCS34725 are the two sources that must never miss a sample: yaw is integrated,
and a floor line lasts a couple of centimetres at speed. Reading them from the
task that already runs at a fixed tick, and waking that task with the sensors'
own INT pins, gives us the exact `dt` between samples instead of whatever the
scheduler felt like. The code still supports moving them to the Pi's I2C by
changing one word, which is how we tested that the decision was the right one.

**One I2C bus, 400 kHz, and interrupts that never touch it.** The ISRs only
stamp `micros()` and wake the sensor task — calling `Wire` inside an interrupt
is how you hang a bus.

## Safety, in the order things react

1. The navigator brakes on its own when the corridor closes (it sees the wall
   coming, in millimetres, not pixels).
2. The escape manoeuvre backs the car out if it gets stuck.
3. The servo limits are compile-time constants and get applied three times: on
   conversion, on ramping, and on writing to the pin. A servo command out of
   range breaks the steering rack, and we broke one that way.
4. The ESP32 watchdog: if the control task or the Pi goes quiet, the motor stops.
5. The car always boots **disarmed**.
6. The button latches a local cut inside the ESP32: pressed while the car is
   armed, the motor dies on the next 10 ms tick, without waiting for the Pi and
   even if the Pi is hung.

## Rules the wiring has to satisfy

| Rule (WRO 2026 Future Engineers) | How we meet it |
|---|---|
| One driving motor connected to the axle through gearing, one steering actuator | Single DC motor → 2:1 gearing → rear axle; MG996R on the steering rack |
| No differential-drive base | Ackermann steering with a mechanical differential; no independent left/right drive |
| No radio, Bluetooth or Wi-Fi while the vehicle runs | The ESP32 firmware has no Wi-Fi stack at all. The Pi's access point and web panel are bench tools and get shut down before the round |
| One switch to power on, one start button | Main switch on the battery rail; one push button on GPIO 13 that arms and starts, and disarms and stops |
| Wired connections only between components | USB and jumper wires; nothing on the car talks over the air |

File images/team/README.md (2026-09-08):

# Team photos

Two photos, as the WRO template asks:

| File | What it is |
|---|---|
| `team-official.jpg` | The two of us with the car. Plain background, faces visible |
| `team-funny.jpg` | The same two, less serious |

> **TODO (team):** take both. Landscape, good light, the car in the frame and in
> focus. These are the first thing a judge sees on the repository page.

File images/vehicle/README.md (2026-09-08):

# Vehicle photos

The rules ask for the vehicle from every side, from the top and from the bottom.
Six files, named so nobody has to guess:

| File | View |
|---|---|
| `front.jpg` | Front — camera and steering visible |
| `back.jpg` | Rear — motor, gearing and drive axle |
| `left.jpg` | Left side |
| `right.jpg` | Right side |
| `top.jpg` | From above — electronics layout |
| `bottom.jpg` | From below — chassis, axle, wiring runs |

> **TODO (team):** take the six. White or plain background, same distance and
> the same light for all six, car fully in frame, no hands. A ruler or a 5×5 cm
> pillar next to the car in one of them gives the judge a sense of scale for
> free.

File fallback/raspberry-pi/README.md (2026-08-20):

# Carro WRO 2026 — Futuros Ingenieros

Raspberry Pi 5 (visión y decisiones) → ESP32 (hardware) → puente H → motor.
Mismo código en Windows 11 y en Raspbian, Python 3.11.

```
reconizer/
├── main.py                     ← el programa principal
├── config/
│   ├── colors.json             ← las últimas 5 calibraciones de color
│   └── robot.json              ← puerto, límites, ganancias, red
├── src/
│   ├── color_config.py   perfiles de color (guardado atómico)
│   ├── camera.py         cámara USB igual en los dos sistemas
│   ├── vision.py         máscaras HSV y detección de objetos
│   ├── protocolo.py      trama binaria hacia el ESP32
│   ├── enlace.py         hilo serie con autodetección de puerto
│   ├── imu.py            MPU6050 opcional por I2C
│   ├── navegacion.py     perfil del muro y estrategias de esquive
│   ├── robot.py          el núcleo que lo une todo
│   ├── robot_config.py   robot.json
│   └── servidor.py       carrito.local: vídeo + control desde el móvil
├── tools/
│   ├── calibrador.py     interfaz de calibración HSV
│   ├── panel.py          panel de pruebas de escritorio
│   ├── selftest.py       51 pruebas de visión, sin cámara
│   ├── selftest_robot.py 102 pruebas del sistema, sin carro
│   ├── test_firmware.cpp 49 pruebas de la lógica del ESP32, sin ESP32
│   └── carrito_wifi.sh   AP, mDNS, UART, I2C y servicio de arranque
└── firmware/esp32_carro/
    ├── esp32_carro.ino   firmware nuevo (sin WiFi)
    ├── protocolo.h       gemelo en C++ de protocolo.py
    └── seguridad.h       límites del servo y del motor
```

---

## Puesta en marcha

**Raspberry Pi 5**

```bash
sudo bash tools/carrito_wifi.sh instalar   # avahi, UART, I2C, hostname carrito
sudo reboot
python3 -m venv .venv && source .venv/bin/activate
pip install -r requirements.txt
python3 tools/selftest.py && python3 tools/selftest_robot.py
sudo bash tools/carrito_wifi.sh ap         # crea la red Carrito-WRO
python3 main.py --sin-panel
```

**Windows 11** (desarrollo, sin carro)

```bat
.venv\Scripts\activate
pip install -r requirements.txt
python tools\selftest.py
python tools\selftest_robot.py
python main.py --simulado --imagen capturas\pista.png
```

**ESP32**: abre `firmware/esp32_carro/esp32_carro.ino` en el IDE de Arduino
(los tres archivos tienen que estar en la misma carpeta) y súbelo. Ya no hace
falta ninguna librería externa: fuera WiFiManager, WebSockets y ESPmDNS.

**Cableado del serie** (cruzado, ambos a 3,3 V, sin divisor):

| Raspberry Pi 5 | ESP32 |
|---|---|
| GPIO14 / TXD (pin 8) | GPIO16 (RX2) |
| GPIO15 / RXD (pin 10) | GPIO17 (TX2) |
| GND (pin 6) | GND |

También funciona por USB sin tocar nada: el firmware escucha las dos bocas y
contesta por la que recibió la última trama válida.

---

## Cómo se usa

Enciende, entra a **http://carrito.local:8080/** desde el móvil (o
`http://192.168.50.1:8080/` si el mDNS no resuelve) y verás lo que ve el carro
con el muro detectado, el perfil de distancia, por dónde pasan las ruedas y la
decisión que está tomando. Desde ahí armas, paras, cambias la velocidad máxima,
la estrategia y las ganancias, en caliente.

El panel de escritorio (`main.py` lo abre solo si hay pantalla) muestra lo mismo
más los parámetros finos que en el móvil estorban.

**El carro arranca siempre DESARMADO.** Hay que pulsar ARMAR para que el motor
pueda moverse. `Escape` en el panel y el botón rojo en la web son parada de
emergencia.

Para limitar la velocidad de esta prueba: el slider *vmax* (0-255) es el tope de
PWM que el ESP32 no supera nunca, y *crucero* / *en giro* son porcentajes de ese
tope. `python3 main.py --vmax 90` lo fija desde la línea de órdenes.

---

## Cómo no chocar con los muros: qué opciones hay

Lo exploré en `src/navegacion.py`, que lleva el razonamiento completo. Resumen:

| Opción | Qué tal | Estado |
|---|---|---|
| **Área de negro en dos ventanas** | Cuatro líneas, pero el muro del fondo (lejos, inofensivo) pesa igual que el de al lado (cerca, peligroso). No distingue distancia. | Descartada |
| **Perfil de contacto muro-piso, columna por columna** | Para cada columna, el píxel negro más bajo es donde el muro toca el suelo: cuanto más abajo, más cerca. Sale un perfil de distancia de ancho completo, como un LIDAR pobre. | **Implementada, por defecto** |
| **Seguir una pared a distancia fija** | Trayectorias muy limpias y repetibles, pero hay que decirle qué pared y se pierde si esa pared desaparece. | **Implementada, seleccionable** |
| **Vista de pájaro (homografía) + pure pursuit** | Es lo "correcto" y lo que hacen los equipos fuertes, pero exige calibrar la homografía con un patrón. El perfil de arriba ya es su entrada natural. | Siguiente paso |
| **Giroscopio como rumbo** | La pista es un cuadrado: los giros son de 90° exactos. La cámara decide *cuándo* girar, el giroscopio decide *cuánto*. Es lo que más sube la fiabilidad. | **Implementada como capa encima** |
| **Ultrasonidos laterales** | Un muro de 100 mm visto en ángulo rebota el eco hacia otro lado y devuelve "sin obstáculo" justo cuando vas a chocar. | Solo como red de último metro |

Tu idea de medir el negro en la franja central en vez del píxel más bajo está
generalizada: se mide en **todas** las columnas y luego se agrega por zonas
(izquierda / pasillo de las ruedas / derecha). Las dos líneas verticales
blancas del vídeo son por dónde pasan las ruedas, calibrables con `rueda izq` y
`rueda der` porque la cámara no las ve.

La capa de **seguridad** es independiente de la estrategia: si el pasillo de las
ruedas baja de `frenar_bajo` se reduce la velocidad, y si baja de `parar_bajo`
el carro retrocede girando al revés para reencuadrar. Eso corre siempre,
incluso en modo manual: no te deja empotrar el carro aunque se lo pidas.

### Parámetros que vas a tocar en la pista

| Parámetro | Qué hace |
|---|---|
| `girar_bajo` | Espacio libre por debajo del cual asume que hay esquina y gira |
| `frenar_bajo` / `parar_bajo` | Dónde empieza a frenar y dónde se planta |
| `kp` / `kd` | PD del centrado. Sube `kp` si va lento a corregir, sube `kd` si oscila |
| `dir_giro` | Cuánto vuelca la dirección en las esquinas |
| `min_recto_ms` | Espera mínima entre dos esquinas: evita que encadene giros sobre sí mismo |
| `px_min_columna` | Píxeles negros mínimos en una columna para creerse que hay muro |
| `ignorar_abajo` | Franja inferior tapada por el chasis |

---

## El giroscopio (opcional de verdad)

El MPU6050 va al **I2C de la Raspberry**, no al ESP32: escupe cientos de
muestras por segundo y lo que hace falta es integrarlas y filtrarlas, no
reaccionar a cada una. Metiendo eso en el ESP32 le robas tiempo al lazo de
control, que sí es crítico. En la Pi corre en su propio hilo a 100 Hz y cuesta
menos del 2% de un núcleo.

```
VCC -> pin 1 (3V3)     SDA -> pin 3 (GPIO2)
GND -> pin 6 (GND)     SCL -> pin 5 (GPIO3)
```

Comprueba con `i2cdetect -y 1` (debe salir `68` o `69`). Si no está, si el bus
no existe (Windows) o si se suelta un cable a mitad de carrera, el programa
sigue igual, solo que sin ayuda de rumbo — está probado.

**Calibra el giroscopio con el carro quieto** (botón *Calibrar* en el panel o en
la web) cada vez que enciendas. Sin eso el yaw se va solo 1-3 grados por segundo
y a la tercera recta el rumbo objetivo ya no significa nada.

---

## El enlace con el ESP32

Trama de 11 bytes, binaria, con CRC:

```
A5 5A | LEN | TIPO | payload | CRC8
```

`vel` y `dir` viajan en **porcentaje con signo**, no en unidades de hardware: la
Pi no sabe nada de grados de servo ni de PWM. El mapeo lo hace el firmware, que
es quien conoce los límites físicos. Por eso un bug en la Pi no puede pedir un
ángulo imposible: no existe forma de expresarlo en el protocolo.

Por qué binario y no texto: un `A95\n` obliga a parsear en el ESP32 mientras el
motor espera, y un byte de ruido convierte `A95` en `A9` (el servo se va a 9
grados). Con LEN y CRC, una trama con ruido simplemente no existe.

`protocolo.py` y `protocolo.h` son gemelos y `selftest_robot.py` cruza vectores
generados por el binario de C++ contra los de Python: si alguien toca uno solo,
la prueba falla.

---

## Seguridad: quién reacciona antes

1. **El navegador** frena cuando ve que el pasillo se cierra.
2. Si el lazo de visión se atasca **>250 ms**, el hilo del enlace manda
   velocidad 0. No repite la última orden: repetir una orden vieja es
   exactamente lo que hace que un carro siga a fondo contra la pared.
3. Si el serial se calla **>300 ms**, el ESP32 corta el motor y **centra el
   servo** (el carro se detiene recto, no torcido).
4. Si la tarea de control del ESP32 se cuelga **>200 ms**, una tarea vigilante
   de prioridad máxima corta el PWM directamente sobre el hardware.
5. Ctrl+C, cerrar la ventana o perder la cámara mandan parada de emergencia.

### La última línea de defensa del servo

En `firmware/esp32_carro/seguridad.h`, `SERVO_TOPE_MIN = 50` y
`SERVO_TOPE_MAX = 145` son constantes de compilación. La configuración en
caliente solo puede **estrechar** ese rango, jamás ampliarlo. El límite se
aplica **cuatro veces**: al convertir el porcentaje a grados, al recortar contra
izquierda/derecha, dentro de la rampa, y otra vez justo antes de escribir el
LEDC. La prueba `test_firmware.cpp` barre porcentajes de -1000 a +1000 y
comprueba que ninguno se sale.

Además el servo tiene **límite de grados por segundo** (320 por defecto): un
MG996R yendo de 65 a 135 de golpe arranca la cremallera.

Y el motor **nunca invierte el giro sin pasar por cero y esperar 150 ms**.
Invertir un puente H a plena marcha es un pico de corriente que, además, el
reglamento WRO limita a 4 A.

---

## Calibrar los colores

```bash
python3 tools/calibrador.py                     # cámara 0
python3 tools/calibrador.py --imagen foto.png   # sobre una foto
```

1. Elige el color: `rojo`, `verde`, `negro` (los que se usan) y `magenta`,
   `naranja`, `azul` (estacionamiento y líneas del piso, listos para cuando
   toquen).
2. **Clic izquierdo sobre el objeto**: calcula el rango HSV solo. Con *acumular*
   activado cada clic amplía la muestra — haz clic en la cara iluminada y en la
   sombreada del mismo pilar.
3. Afina con los sliders; cada uno tiene su casilla para escribir el valor exacto.
4. Nombre y **Guardar perfil**. Se conservan las 5 últimas.

Los perfiles guardados antes de que existieran los colores nuevos los heredan
solos, sin pisar lo que ya tenías calibrado.

**Congela la exposición y el balance de blancos de la cámara** antes de
calibrar. Si siguen en automático, al girar hacia una pared blanca la cámara
reajusta y tu calibración HSV deja de valer.

---

## Reglamento que condiciona todo esto

Futuros Ingenieros 2026: tapete 3200×3200 mm con pista interior de 3000×3000 mm,
piso blanco, muros exteriores e interiores de 100 mm de alto y negros por
dentro, 7 señales verdes y 7 rojas de 5×5×10 cm. Robot máximo 30×20×30 cm,
hardware y software libres.

---

## Qué sigue

1. Probar vueltas a la pista vacía y ajustar `girar_bajo` y `kp`/`kd`.
2. Contar vueltas con las líneas naranja y azul del piso (los colores ya están).
3. Reto de obstáculos: pasar el rojo por la derecha y el verde por la izquierda,
   usando `Deteccion.base_y` como distancia y `desviacion()` como error lateral.
4. Estacionamiento en la zona magenta.

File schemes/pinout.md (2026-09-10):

# Pinout and bus map

Everything here was read straight out of the firmware we actually flash
(`main/firmware/esp32/esp32_carro.ino`, identical to `fallback/`'s), so it matches the car on the
table, not a plan we never built.

## ESP32 (hardware controller)

| Signal | ESP32 pin | Goes to | Notes |
|---|---|---|---|
| `RPWM` | GPIO 25 | IBT-2 (BTS7960) RPWM | Motor PWM, 20 kHz, 8-bit. 20 kHz keeps it out of the audible range |
| `LPWM` | GPIO 26 | IBT-2 (BTS7960) LPWM | The other direction |
| `R_EN` | GPIO 27 | IBT-2 R_EN | Held HIGH while the car is armed |
| `L_EN` | GPIO 33 | IBT-2 L_EN | Held HIGH while the car is armed |
| `SERVO` | GPIO 32 | MG996R signal | 50 Hz, 16-bit resolution, 500–2400 µs |
| `SDA` | GPIO 21 | MPU-6050 + TCS34725 | Shared I2C at 400 kHz |
| `SCL` | GPIO 22 | MPU-6050 + TCS34725 | Same bus |
| `INT_TCS` | GPIO 19 | TCS34725 INT | Open-drain, active LOW, internal pull-up. Optional |
| `INT_MPU` | GPIO 18 | MPU-6050 INT | Push-pull, active HIGH. Optional |
| `BOTON` | GPIO 13 | Push button to GND | Arm/start and disarm/stop. Internal pull-up, no resistor, two wires |
| `LED_ESTADO` | GPIO 2 | Status LED | Shows armed / disarmed / cut by the button |
| `RX2` | GPIO 16 | Raspberry Pi GPIO 14 (TX) | Alternative link if we do not use USB |
| `TX2` | GPIO 17 | Raspberry Pi GPIO 15 (RX) | Crossed, 115200 baud |

I2C addresses: MPU-6050 at `0x68` (or `0x69`), TCS34725 at `0x29`.

The two INT lines are optional on purpose. If we do not wire them the firmware
notices by itself and falls back to polling — slower and with more jitter, but
the car still runs. That was deliberate: during a competition weekend a broken
jumper should cost us precision, not the round.

## Raspberry Pi 5

| Port | Connected to |
|---|---|
| USB 2.0 | WN-L1812.K56R camera (IMX179 sensor, UVC, MJPG) |
| USB 2.0 | ESP32 (this is the link we normally use: data + power for the ESP32) |
| GPIO 14 / 15 (UART) | ESP32 GPIO 16 / 17, only if the USB link is not used |
| USB-C | 5 V input |

The firmware listens on **both** mouths at the same time and answers through the
one the last valid frame came from, so the same binary works over USB or over
the GPIO UART with no recompile.

## Link protocol

Binary frames with CRC, firmware version 4. Commands go Pi → ESP32 at ~100 Hz,
telemetry comes back at 20 Hz (motor/servo state) and 40 Hz (yaw + colour).
Line crossings travel as **counters**, not as events, so a dropped frame never
loses a crossing.

If the Pi goes quiet for 300 ms the ESP32 stops the car on its own. That
failsafe is the whole reason the ESP32 sits in the middle instead of hanging the
driver straight off the Pi.

## Still to confirm

> **TODO (team):** the power side of the table — battery chemistry and capacity,
> the regulator feeding the Pi, the rail feeding the servo, and the fuse (if
> any). Fill in `power-budget.md` and the power block of `wiring-diagram.svg`.

The button travels inside the sensor frame, whose payload grew from 14 to 15
bytes in firmware 4. The Pi accepts both sizes, so an ESP32 with older firmware
still talks — it just has no button.

GPIO 13 was chosen because it is not a strapping pin and not input-only: a
button held down at power-up cannot stop the ESP32 from booting.

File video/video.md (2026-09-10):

# Videos

The rules ask for a video of at least 30 seconds per challenge, showing the
vehicle driving autonomously, on a public link.

| Round | Link | Length |
|---|---|---|
| Open Challenge | [Green Tech Momboy — WRO Open Challenge](https://youtu.be/Z215ovmq5Jg) | 0:40 |
| Obstacle Challenge | [Obstacle round](https://youtube.com/shorts/VIz5sVFtg74) | 1:38 |

Both are public and both are over the 30 s minimum. What we wanted in each one,
and what we told ourselves every time we forgot:

- One continuous shot. A cut in the middle of a lap reads as a hidden retry.
- Start with the car switched off, so the single switch and the start action are
  on camera.
- Film the whole track, not the car — a judge wants to see it pass the sections.
- Say the direction and the track width at the beginning; both change per round.

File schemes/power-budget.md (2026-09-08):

# Power budget

> **Status:** the topology below is what the car is built around. The numbers in
> the "typical" column are datasheet / vendor figures, **not** our measurements,
> and the battery row is still to be filled in by the team. We are keeping the
> two apart on purpose: a documentation table that mixes what you measured with
> what you copied is worth nothing when something browns out at the venue.

## Rails

```
BATTERY  ──▶ main switch ──┬──▶ IBT-2 (BTS7960)  B+/B-   ──▶ DC motor
                           │
                           ├──▶ regulator 5 V  ──┬──▶ Raspberry Pi 5 (USB-C)
                           │                     │        └─▶ camera (USB)
                           │                     │        └─▶ ESP32 (USB)
                           │                     │
                           │                     └──▶ MG996R servo (5–6 V)
                           │
                           └──▶ (common ground with everything above)
```

Two things we learned the hard way and that this drawing has to keep true:

- **The motor and the sensors must not share a soft rail.** On an early
  prototype the ESP32 probed for the MPU-6050 and the TCS34725 right after
  `Wire.begin()`, while the motor start-up was pulling the rail down, and both
  sensors came back as "absent" *for the rest of the run*. We fixed it in
  firmware (wait 250 ms, retry every 3 s, plus a manual retry button in the
  panel), but the real fix is electrical: keep the logic rail stiff.
- **The servo is the spiky load, not the motor.** An MG996R under a steering
  correction pulls hard for a few tens of milliseconds. If it sags the 5 V rail
  the Pi is the one that reboots, and losing the Pi mid-round means losing the
  round.

## Consumers

| Load | Voltage | Typical (datasheet / vendor) | Measured on our car |
|---|---|---|---|
| Raspberry Pi 5 (8 GB), OpenCV running | 5 V | 3–5 A peak | **TODO** |
| USB camera WN-L1812.K56R | 5 V (from Pi) | ~0.2 A | **TODO** |
| ESP32 dev board | 5 V (from Pi USB) | 0.15–0.5 A on peaks | **TODO** |
| MPU-6050 + TCS34725 | 3.3 V (from ESP32) | ~0.02 A together | **TODO** |
| Servo MG996R | 5–6 V | ~0.5–0.9 A moving, ~2.5 A stalled | **TODO** |
| DC motor through the IBT-2 | battery | depends on the surface | **TODO** |

> **TODO (team):** battery pack — chemistry, cell count, nominal voltage,
> capacity, BMS, and how long a full charge lasts in practice (that last one is
> the number that decides how many practice rounds we get between charges).
> Also: main switch model and position, and whether there is a fuse.

## How we plan to measure it

1. Bench first, with the wheels in the air: `python3 main.py --vmax 70`, a USB
   meter on the Pi and a clamp meter on the battery lead.
2. Then a full three-lap round with the same instruments, logging the worst
   instantaneous draw and the resting voltage right after the round.
3. Repeat at the end of a practice session, with the pack half empty — brownouts
   show up at low state of charge, not at full charge.

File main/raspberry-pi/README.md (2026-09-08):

# Piloto WRO 2026 — Open Challenge + deteccion de obstaculos

Sistema nuevo del carro (GreenTech Momboy). Sustituye a `reconizer` tomando lo
que funcionaba (navegacion centrada, calibracion por clic, enlace binario con
el ESP32) y arreglando lo que fallaba (paredes con brillo, objetos detectados
por encima del muro, conteo de esquinas).

```
Raspberry Pi 5 (vision + decisiones)  <-USB->  ESP32 (motor, servo, MPU6050, TCS34725)
```

El firmware del ESP32 vive en `code/esp32_carro/` (protocolo v2: lee el
MPU6050 y el TCS34725 por I2C y manda yaw, cruces de linea y el estado de los
el estado del pulsador de competencia a la Pi).

---

## Puesta en marcha

**Raspberry Pi 5** (o PC Windows para probar sin carro):

```bash
python3 -m venv .venv && source .venv/bin/activate    # en Windows: .venv\Scripts\activate
pip install -r requirements.txt
python tools/selftest.py            # 323 pruebas, sin hardware
python main.py                      # camara + ESP32 + web
python main.py --simulado           # sin ESP32 (pruebas en el PC)
python main.py --imagen foto.jpg    # sin camara, sobre una foto
python main.py --vmax 90            # tope de PWM solo para esta prueba
./piloto.sh arrancar                # COMPETENCIA: demonio sin web (SSH/VNC)
```

**ESP32**: abrir `code/esp32_carro/esp32_carro.ino` en el IDE de Arduino (los
6 archivos en la misma carpeta) y subir. Sin librerias externas. Al subir
firmware nuevo, subirlo ANTES de correr `main.py`. **El pulsador necesita
la version 4** (la trama de sensores paso de 14 a 15 bytes); con firmware
viejo todo lo demas sigue igual, pero el boton no llega.

Web de depuracion: **http://carrito.local:8080/** (o `http://<ip>:8080/`).
El carro **arranca desarmado**: pulsar ARMAR. En modo auto, ARMAR arranca la
carrera (cronometro + conteo).

En competencia no hay web: manda **el pulsador** que cuelga del ESP32 (la
misma pulsacion arma y desarma) y el **LED azul** dice en que estado esta el
carro; el programa se lanza como demonio con `./piloto.sh arrancar`. Ver
[El boton y el LED](#el-boton-y-el-led-el-start-del-reglamento) y
[Correr sin la web](#correr-sin-la-web-el-demonio-ssh-y-vnc).

---

## Que hace en el Open Challenge (reglas 2026)

1. **Sentido de la ronda**: en 2026 las 3 vueltas van TODAS en la misma
   direccion (ya no hay media vuelta) y esta prohibido meterle datos al robot
   antes del start, asi que el carro lo deduce solo:
   - por la **primera linea** de esquina que cruza (TCS bajo el carro o
     camara): naranja primero = horario, azul primero = antihorario
     (`lineas.naranja_es_horario` por si un tapete viniera al reves);
   - por la camara ANTES de cruzar (ve cual linea esta mas cerca);
   - de respaldo, por el lado del primer giro.
   Tambien se puede forzar desde la web para pruebas.
2. **Mantenerse en el carril**: estrategia `centrado` (la probada) o `pared`
   (seguir el muro interno a distancia fija). El giroscopio corrige el rumbo
   en recta y clava los giros de 90.
3. **Esquinas**: PRE_GIRO (frena + deja pasar las ruedas traseras + **giro
   abierto** tipo camion si hay sitio) -> GIRO de 90 por giroscopio -> RECTO.
   Disparadores: **linea del piso cruzada** (el mas fiable), pasillo
   cerrandose, o muro interno que desaparece. Ver "El bucle de las esquinas".
4. **Conteo**: una esquina se ABRE con su primera linea y se queda esperando
   a la otra, que la CIERRA (nunca abre otra: ver "El giro fantasma"). Cuenta
   una sola vez, la den por buena las lineas o el giro de 90. Si se ve el par
   entero se comprueba ademas el ORDEN, que en las cuatro esquinas es el mismo
   (horario: naranja y luego azul): un par al reves o es basura o el carro se
   dio la vuelta, asi que uno suelto no cuenta y dos seguidos invierten el
   sentido. 4 esquinas = vuelta. Alternativa: **modo de esquina por color**
   (`esquina_color.activo`): solo cuenta el color del sentido, el otro se
   ignora, y el giro se suelta al ver un pilar. Ver su seccion mas abajo.
5. **Parada final**: tras la esquina 12 avanza `carrera.parada_ms` para meter
   el carro ENTERO en la seccion de meta y se detiene solo (bono del
   reglamento). Tope de 3 minutos.

**Obstaculos (basico, apagado por defecto)**: `obstaculos.activo` en la web.
Pilar rojo se pasa por la derecha, verde por la izquierda; el punto de paso se
calcula en mm reales y se recorta al hueco libre del perfil.

---

## El arreglo de las paredes con brillo (lo importante)

El programa viejo buscaba "el pixel negro mas bajo" por columna. Cuando la
pared brillaba dejaba de ser negra: la linea de contacto saltaba a las sillas
del fondo y el carro creia que tenia via libre (capturas 514/515).

El metodo nuevo (`muro.metodo = piso`) usa dos ideas geometricas:

1. **Horizonte**: con la camara a 125 mm y 7.5 grados, TODO lo que es pista
   queda por debajo de una fila fija de la imagen. Sillas, mesas y publico se
   recortan por geometria antes de mirar un solo color.
2. **Primera transicion piso -> no-piso, subiendo desde abajo**: solo se
   supone que el PISO parece piso (blanco o linea naranja/azul). La pared
   puede brillar o ser gris: mientras no parezca piso blanco, se encuentra su
   base igual. Y como se toma la PRIMERA transicion, nada del fondo puede
   adelantarse.

Encima se ajustan **rectas** al contorno (en mm reales) que se fusionan a
traves de los huecos por brillo, y sus intersecciones dan las **esquinas**
("saliente" = canto del muro interno, "rincon" = esquina del externo).

El metodo viejo sigue disponible (`muro.metodo = negro`) para comparar en
pista. `tools/selftest.py` incluye un caso sintetico donde el viejo falla y
el nuevo no.

---

## El bucle de las esquinas (y por que las lineas lo arreglan)

Sintoma: al llegar a la curva el carro se queda dando vueltas dentro de ella,
como si el hueco fuera el camino.

Causa: cuando el muro interno se acaba deja un hueco de piso blanco enorme.
Para cualquier navegacion por espacio libre ese hueco **es** el camino: el
carro se mete, desde la posicion nueva vuelve a ver otro hueco, se vuelve a
meter, y nunca sale. No es un problema de umbrales; la vision esta
contestando bien a la pregunta equivocada. En una captura real de esquina el
pasillo mide 1064 mm de via libre justo cuando hay que doblar.

Arreglo, en tres piezas:

1. **La linea del piso dice donde esta la curva** (`linea_dispara_esquina`).
   Cruzar la primera linea del par ENTRA en la esquina por si solo, sin
   esperar a que el pasillo se cierre. Es informacion fisica, no inferencia.
2. **Anti-bucle** (`bloqueo_esquina`): mientras el carro esta dentro de la
   curva, el giro de 90 se ejecuta comprometido y la camara no puede
   redirigirlo. Se termina por angulo de giroscopio o por timeout, nunca
   porque se vea un hueco tentador. La vision sigue mandando en la seguridad.
3. **Una esquina, un giro**: la curva ya girada no vuelve a disparar aunque
   la zona siga activa. Sin esto el carro encadenaba dos giros de 90 seguidos
   (180 grados) y se metia en la pared.

Se sale de la zona al completar el giro, y hay un timeout
(`lineas.esquina_max_ms`) por si el giroscopio falla: nadie se queda
bloqueado "en la esquina" para siempre.

La zona se marca tambien cuando el giro nace de la vision, asi que el
anti-bucle protege aunque el TCS no este montado o las lineas no se vean.

En la web: caja **Esquinas** de la pestaña Carrera, con un boton *Probar
esquina* que inyecta un cruce de linea para ensayar la maniobra en el banco
sin empujar el carro. Mientras el carro esta en la curva el video se enmarca
en naranja.

## Que recta es cada pared (y por que hace falta el giroscopio)

Sintoma: el carro cruza la esquina, esquiva un pilar que lo empuja hacia la
esquina interna y llega TORCIDO. Ahi ve las dos rectas a la vez -- la del
tramo que deja y la del que entra -- y se desorienta: toma la pared de
enfrente por la de su carril.

El angulo de una pared MEDIDO DESDE EL CARRO no sirve para distinguirlas,
porque cambia con lo torcido que vaya. El angulo respecto a la PISTA si, y
pasar de uno a otro solo necesita cuanto se ha desviado del rumbo de la recta,
que es justo lo que da el giroscopio:

    angulo_pista = angulo_carro - desvio_de_rumbo

Con eso, ~90 grados es una pared LATERAL (la de tu carril) y ~0 es la pared de
FRENTE (el fondo de la curva), aunque el carro vaya cruzado 45 grados. Y basta
con ver UNA pared para saber cual es: no hace falta ver las dos.

Medido sobre la escena sintetica del selftest, con el carro cruzado 45:

| | sin giroscopio | con giroscopio |
|---|---|---|
| pared de enfrente | no la reconoce (`otro`) | `frontal` a 1100 mm |

Sin giroscopio el fallo es SEGURO (no sabe) y no peligroso (confundirse): al
salirse de la tolerancia, la pared se marca `otro` y no se usa.

Que se hace con eso:

- `interna_mm` / `externa_mm`: distancia a la pared de tu carril, resuelta con
  el sentido de la ronda (en horario la interna es la derecha).
- `frontal_mm`: la pared cruzada. Dispara la esquina por si sola, y es un
  disparo POSITIVO: no se confunde con una pared lateral vista de refilon.
- La estrategia `pared` sigue la interna identificada en vez de la media de la
  banda de la imagen, que en una curva mezcla las dos rectas.

En el video: verde = pared lateral (con `lat izq` / `lat der`), rojo = pared
de FRENTE, gris = tramo sin orientacion clara. Debajo, la linea
`int ... | ext ... | frente ... | desvio ...`. Se apaga con
`navegacion.usar_rectas`.

## Giro de 90 en dos tiempos (para no perderse obstaculos)

`giro2t.activo`. En vez de doblar de una sola pasada, el carro **avanza en
diagonal y luego retrocede con la direccion invertida**. Con direccion
Ackermann el sentido de rotacion es el mismo en los dos tramos (es la
maniobra de dar la vuelta en una calle estrecha), asi que gira casi sobre el
sitio y termina **alineado con el tramo nuevo**, viendo el pasillo entero de
frente. Eso es lo que evita que un pilar se quede fuera de cuadro y el carro
se lo salte.

**SOLO se ejecuta en una esquina confirmada por el PAR DE LINEAS del piso**
(TCS o camara). Es la unica maniobra del carro que retrocede, y retroceder en
mitad de una recta -- porque la vision creyo ver una esquina donde no la hay --
es meterse contra lo que venga detras. Sin esa prueba fisica se hace el giro
normal, que solo va hacia adelante. Si la zona de esquina caduca a mitad de la
maniobra, la reversa se corta en el acto y los grados que falten se completan
hacia adelante. (Consecuencia practica: con el TCS sin montar y las lineas mal
vistas, el giro de dos tiempos no llega a usarse nunca.)

El **escape de seguridad** es otra cosa y no lleva ese candado: es la ultima
red contra un choque y tiene que poder retroceder este donde este.

Es mas lento y necesita giroscopio (mide el angulo acumulado paso a paso, no
por diferencia contra el inicio, que se envuelve). Sin MPU cae solo al giro
normal. Si le faltan grados repite avance+reversa hasta `max_ciclos`.

El retroceso esta acotado por `reversa_max_ms`: el reglamento solo permite ir
marcha atras dentro de la seccion y la vecina, y esta maniobra no debe cruzar
el limite hacia atras. El escape de seguridad no interrumpe la maniobra (ella
lleva su propia reversa); corta sola en `min_pasillo_mm`, que va por encima
de `parar_bajo_mm`.

## El giro fantasma de la azul que llega tarde

Sintoma: al cruzar la naranja el carro giraba bien, pero rato despues -ya con
el giro hecho- aparecia la azul y disparaba OTRO giro de 90, a veces hacia el
lado contrario y encima entre pilares.

Causa: el codigo trataba cada linea por separado. Si la azul llegaba fuera de
la ventana del par (se detecta bastante peor que la naranja: es mas oscura y a
la velocidad de paso cae entre dos muestras del sensor), se tomaba por la
PRIMERA linea de una esquina nueva. Y al emparejarse desfasada salian pares
"al reves", que a los dos acababan invirtiendo el sentido de la ronda.

Ahora una esquina se **abre** con su primera linea y se queda esperando a la
otra:

```
naranja  -> ABRE la esquina (entra en la zona, dispara el giro de 90)
azul     -> la CIERRA, tarde o temprano; nunca abre otra
naranja otra vez -> rebote en el borde, se ignora
```

La espera dura `lineas.cierre_max_ms` (6 s, toda la curva), muchisimo mas que
la zona de esquina, que se cierra en cuanto termina el giro. **Si la azul no
llega nunca**, la esquina la da por contada el giro de 90 y se sigue esperando
por si aparece, para que cierre esta en vez de abrir una nueva. Una esquina se
cuenta UNA sola vez, la den por buena las lineas o el giro.

Probado: con cuatro esquinas seguidas perdiendo SIEMPRE la azul, la cuenta
sigue dando 4.

## Modo de esquina por color (`esquina_color.activo`)

Dos cosas seguian pasando en pista con el giro normal: (1) al llegar a la
curva el giro de 90 iba **forzado** y se llevaba por delante los pilares de la
salida, y (2) el carro cruzaba la naranja, giraba, luego veia la azul y
**volvia a girar**. Este modo lo resuelve simplificando, no añadiendo: el TCS
solo hace DOS cosas.

```
1a linea de la ronda   -> fija el sentido: naranja = horario, azul = antihorario
cada linea de ESE color -> cuenta una esquina y dispara el giro hacia ADENTRO
                          (horario = derecha)
la del otro color       -> NO EXISTE: ni gira, ni cuenta, ni es "linea reciente"
la misma otra vez       -> rebote (esquina_color.refractario_ms), no cuenta
```

El giro (`GIRO_COLOR`) va hacia adentro con **velocidad variable**: `vel_max_pct`
con el pasillo despejado y `vel_min_pct` con el muro encima, interpolado con
el pasillo. Con giroscopio se termina al clavar los 90 (misma ley que el giro
normal, topada en `dir_pct`); sin el, cuando el pasillo abre; y siempre hay
`max_ms`. Solo va hacia adelante: el ESCAPE sigue por encima.

**Se suelta en el acto al ver un pilar** (`ceder_al_pilar`): en cuanto hay un
pilar en juego -visto por la camara a la distancia que sea, o en el punto ciego
mientras se le adelanta- el navegador pasa a RECTO y el esquive tiene el
volante, sin tocar nada del esquive. Mientras tanto el rumbo de referencia ya
apunta a la recta NUEVA, asi que el giroscopio sigue tirando hacia adentro
(acotado por `yaw_max` y cediendo al pilar). Cuando el pilar lleva
`reanudar_tras_ms` fuera de juego, se **retoma** el giro por los grados que
falten (`reanudar`); si esquivando ya quedo encarado, la esquina se da por
hecha. Si un escape interrumpe el giro, al volver tambien se retoma.

Con el modo encendido no se usan ni el par de lineas ni el giro de dos
tiempos. La esquina se cuenta al **pisar** la linea (antes de girar), asi que
la carrera espera a salir de la zona de esquina antes de arrancar la parada
en meta. El giro de 90 completado ya no cuenta esquina (salvo
`contar_giro_sin_linea`): si el TCS se pierde una linea, esa esquina no suma;
mejor perder una que sumar una. La vision (pasillo cerrandose, pared de
frente) sigue pudiendo disparar este mismo giro por si el TCS falla
(`vision_dispara`); tambien se le puede quitar el voto.

Ojo: si el TCS se pierde la primera naranja y ve la azul, el sentido sale al
reves toda la ronda. Es el precio de usar solo el TCS; con
`carrera.sentido` forzado desde la web no pasa, y ahi cuenta el color de ese
sentido aunque la primera linea vista fuera la otra.

En banco: pestaña Carrera, boton **Esquina por color**, luego *Probar esquina
(linea naranja)* -> debe girar a la derecha; *Simular linea azul* -> debe salir
"ignorada: cuentan las naranja" en la fila *lineas*. El video marca la zona
como "giro por color, cuenta naranja; cede al pilar".

Medido en el selftest (modelo Ackermann): pilar visible entre los ticks 6 y
40 de la curva -> suelta en el tick 6, retoma en el 40, 90 grados clavados en
46 ticks, una sola esquina contada; con el pasillo en 450 mm la velocidad del
giro baja de 40 a 26.

## El giro al lado incorrecto: la recta que se quedo atras

Sintoma en pista (con el modo por color, pero pasa igual con el giro normal):
el carro cruza la naranja y dobla bien, y acto seguido **sigue doblando al
lado contrario**, sin haber pisado otra linea, hasta la esquina o la pared.
Otras veces, en la linea siguiente, gira directamente al lado incorrecto.

Causa: la referencia de rumbo (`rumbo_recta`) solo avanzaba 90 grados cuando
el codigo registraba una esquina. Si el TCS se pierde la linea, el centrado
toma la curva solo por el hueco blanco del muro interno: el carro dobla bien
fisicamente, pero el codigo sigue creyendo que la recta es la de ANTES. El
giroscopio tira al 45 % hacia esa recta vieja, que ahora queda al lado
contrario, y el carro se va a la pared. Y en la linea siguiente el objetivo
se calculaba sumando 90 a esa recta desfasada: giro 90 grados fuera de sitio.
Habia un segundo agujero: `enlace.yaw()` devuelve `None` si la telemetria
lleva mas de 0,4 s sin llegar, y en ese instante el apuntado se saltaba en
silencio; al volver el yaw, el giro "terminaba" con la referencia vieja.

Arreglo (`navegacion.reanclar_rumbo`, encendido):

- **En recta**: si el carro lleva `reanclar_ms` girado entre
  `reanclar_desde_deg` y `reanclar_max_deg` respecto a la recta, **en el
  sentido de la ronda**, eso fue una esquina sin registrar: se adopta la recta
  nueva en vez de tirar hacia la vieja. Girado en contra del sentido no cuenta
  (es esquivar o entrar torcido) y mas alla de 135 tampoco: ahi ya no se
  distingue de una vuelta sobre si mismo y manda el rescate de
  `desvio_max_deg`, como antes. Con el sentido desconocido no se toca.
- **Al apuntar una esquina**: el objetivo sale de la recta REAL (misma regla),
  no de la acumulada. Vale para el giro normal y el giro por color.
- **Sin yaw al entrar**: el giro queda pendiente de apuntar y lo hace en cuanto
  el yaw vuelve, descontando lo girado a ciegas.

Medido en el selftest: tras doblar solo 90 grados, el codigo viejo pedia
-45 % de volante (izquierda, en horario) de forma sostenida; con el re-anclaje
la recta pasa a 90 y el volante queda centrado. En la web sale como *rumbo
re-anclado: N esquina(s) sin registrar* y en el motivo de la decision.

Comprobacion aparte, que el codigo no puede hacer por ti: si en la web
`carrera.sentido` esta forzado a "horario" y corres en antihorario, el modo
por color ignora las azules y gira a la derecha en cada naranja, que en
antihorario es la linea de SALIDA de la curva. Dejalo en AUTO salvo en pruebas.

## Freno ante linea (que el TCS no se la salte)

El TCS integra 24 ms por muestra (`tcs.atime` 246): a velocidad de crucero
una linea de 2 cm deja 1 o 2 lecturas y a veces ninguna. La camara ve la
linea ANTES de que pase bajo el carro (donde la camara ya no llega), asi que
`lineas.frenar_ante_linea` baja la velocidad en recta a `vel_linea_pct` desde
`frenar_desde_mm` de la linea y la mantiene `frenar_tras_ms` despues de que
la linea salga por debajo del cuadro, o de que el TCS avise del cruce.
Funciona aunque `usar_camara` este apagado: la camara solo mide la distancia,
no cuenta ni cruza. En la web: fila *linea vista / freno*.

Si aun asi se pierde lineas, la otra palanca es `tcs.atime` (bajarlo da mas
muestras por linea) y despues **repetir la calibracion del TCS**, porque
cambian todos los valores absolutos.

## Tres lineas de calibracion

Los perfiles (de parametros y de color) van etiquetados en tres listas:
**Open Challenge**, **Esquivar obstaculos** y **Obstaculos + estacionar**.
Cada linea guarda hasta **20** perfiles y se eligen por separado, asi que
afinar el reto de obstaculos no toca la calibracion buena del Open. El
selector esta arriba de cada lista de perfiles; lo que guardes va a la linea
que tengas puesta. Los perfiles que ya existian quedaron en "Open Challenge".

## El esquive: tres cosas que estaban mal

**1. El lado de paso se invertia** (se veia sobre todo en antihorario, pero no
era el sentido). El recorte del punto de paso contra el muro podia dejarlo al
OTRO lado del pilar. Con `margen_mm=261` el despeje pedido son 386 mm, que casi
nunca caben: con el pilar a 300 mm hacia la pared, el objetivo de 686 mm se
recortaba a 260 y el carro se iba a pasar un pilar ROJO por su izquierda.
Pasar por el lado incorrecto **termina la ronda** (regla 9.25.5). Ahora el lado
es intocable: si el hueco no da para el despeje comodo se aprieta hasta el
minimo fisico (medio carro + medio pilar), pero nunca se cruza; y si ni eso
cabe se avisa en pantalla (`no cabe por la derecha`) y manda la seguridad del
muro. El lado sale del COLOR, no del sentido, en horario y en antihorario.

**2. El volantazo.** La correccion de rumbo por giroscopio se sumaba DESPUES
del esquive. Mientras esquivas a proposito te sales del rumbo de la recta, asi
que esa correccion o **suma** (con el esquive topado en 55 % y `yaw_max` en
45 %, el volante llegaba al 100 % y la rueda trasera se llevaba el pilar) o
**resta** (y entonces no esquiva bastante). Con `navegacion.yaw_cede_al_esquivar`
el mantenimiento de rumbo cede en la misma proporcion en que manda el pilar:
medido, el volante pasa de +87 / +23 segun como estuviera cruzado, a +55 en
los dos casos.

**3. Modo de esquive por BORDE** (`obstaculos.modo = borde`). En vez de apuntar
a un hueco en milimetros, se vigila el canto del pilar que da al centro y se le
mantiene sobre una columna objetivo cerca del borde de la imagen
(`borde_frac`): al rojo se le empuja al canto izquierdo y al verde al derecho.
Es control visual puro, no depende de la calibracion de distancias. Al tenerlo
encima (`giro_final_mm`) mete el **giro grande** que lo libra con la cola. Y si
el pilar se sale de cuadro **estando todavia lejos**, se le busca para volver a
encuadrarlo (`buscar_pct`); de cerca no, que de cerca manda el compromiso de
adelantamiento. En el video se ve la linea del canto objetivo y la flecha.

**Memoria del ultimo pilar** (`obstaculos.recordar_lado`, se puede apagar):
guarda color, por que lado habia que pasarlo, donde estaba y a que distancia,
durante `memoria_ms`. Sirve en la curva, cuando el pilar sale de cuadro al
girar y el carro se olvidaba de que lo tenia al lado. Se ve en la telemetria.

## Los pilares de la seccion siguiente no son de esta recta

Las lineas naranja y azul marcan el limite de la seccion. Un pilar que se ve
por DETRAS de ellas esta en el tramo siguiente. Si se le hace caso desde la
recta, el esquive tira del carro justo cuando toca prepararse para la curva:
se pega a la esquina interna, no le queda sitio para abrirse y engancha el
canto al girar.

`obstaculos.limitar_por_lineas` (encendido) descarta los pilares mas lejanos
que la linea mas cercana, con `margen_linea_mm` de holgura para que uno justo
antes de ella siga contando. **En cuanto el carro entra en la zona de esquina
el filtro se levanta** y esos pilares pasan a contar, que es cuando de verdad
hay que esquivarlos. Si no se ve ninguna linea, no se filtra nada.

## Como se pasa un pilar (y los tres fallos que tenia)

**1. Se iba al tope de direccion.** El angulo al punto de paso se calculaba
con la distancia al pilar, asi que al acercarse el mismo desvio lateral pedia
cada vez mas angulo, hasta el tope. Medido con los valores que el equipo tenia
en pista: **96 % de volante a 600 mm y 100 % a 400 mm**, con el pilar poniendo
el 97 % del mando. Arreglado con tres cosas:

- `mirada_min_mm` (350): mirada minima al calcular el angulo. Es lo que impide
  que el volante se dispare de cerca.
- `dir_max_pct` (55): tope de lo que puede pedir el esquive. Un pilar nunca
  deberia mandar el volante a fondo.
- `rampa_dir_pct_s` (220): cuanto puede cambiar por segundo, para que no haya
  volantazo en un solo frame.

**2. La rueda trasera se llevaba el pilar.** Cuando el pilar queda muy cerca
deja de verse: la camara no llega tan abajo. En ese momento el esquive
desaparecia, el centrado tiraba del carro hacia el medio del carril y, con
direccion Ackermann, **la cola corta por dentro** y barre el pilar. Aumentar
el margen no lo arregla: el carro se abre antes y vuelve igual de pronto.

Ahora hay **compromiso de adelantamiento**: desde que el pilar se pierde de
vista se pide RECTO (no se vuelve hacia el) el tiempo que el carro necesita
para adelantarlo con todo su largo, calculado con la velocidad real y el nuevo
`geometria.largo_carro_mm`. Se ve en el video: *ADELANTANDO 0.6s (recto)*.

**3. Un pilar pegado al muro interior lo llevaba de frente contra la esquina.**
Con `peso_max = 1.0` el pilar ponia el 100 % del mando y la evitacion de muros
dejaba de contar justo cuando el muro era el problema. Ahora, con
`ceder_ante_muro`, el peso del pilar **se desvanece segun el pasillo se
cierra**: el muro recupera el mando. Y si el hueco entre el pilar y la pared
es mas estrecho que el carro, se apunta al **centro del hueco** en vez de
elegir un lado y empotrarse (sale avisado en el video).
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

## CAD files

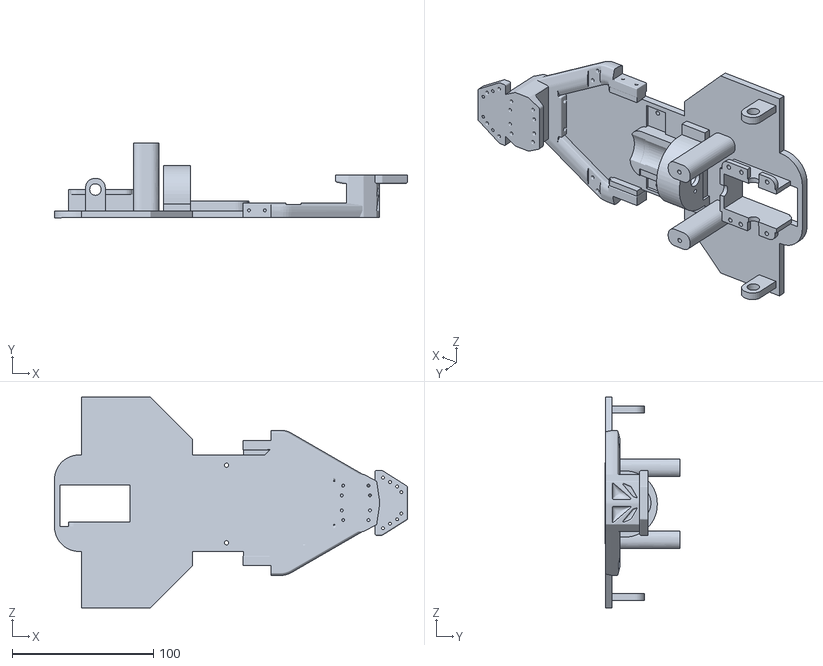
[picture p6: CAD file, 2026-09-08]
3d-model/stl/main base.stl
250.4 x 53.0 x 149.4

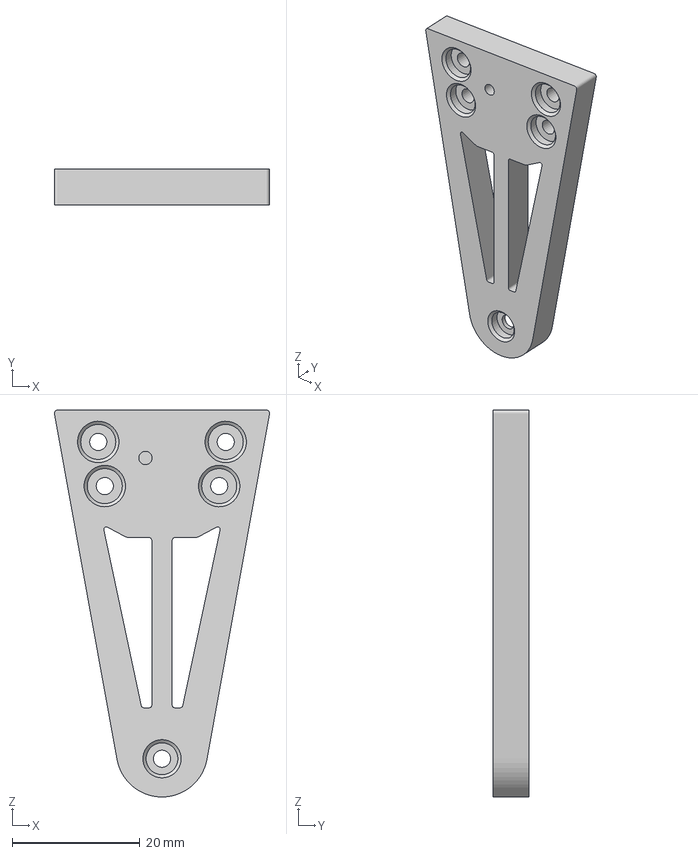
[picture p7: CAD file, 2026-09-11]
3d-model/Documentación 3D/A-Arm/Lower A-Arm Left/Lower A-Arm Left.3mf
33.8 x 5.60 x 60.7 mm

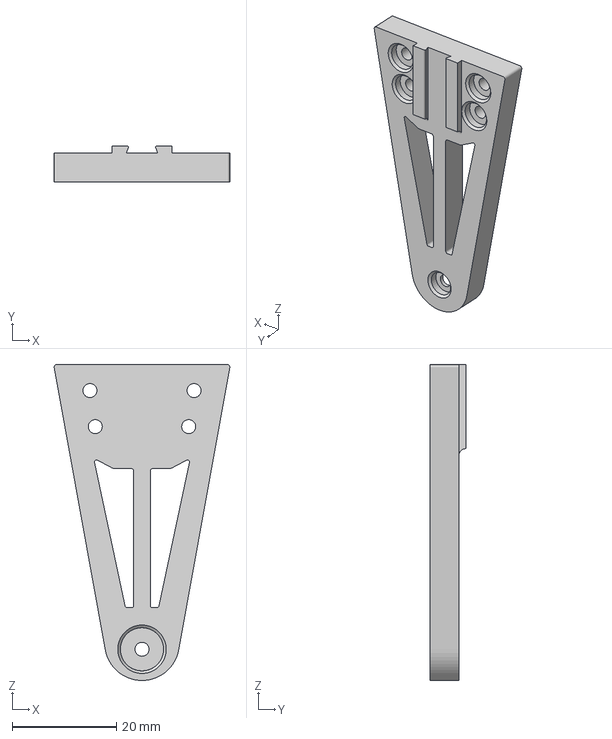
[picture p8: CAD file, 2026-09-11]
3d-model/Documentación 3D/A-Arm/Upper A-Arm (2pcs)/Upper A-Arm Left.3mf
33.8 x 6.97 x 60.7 mm

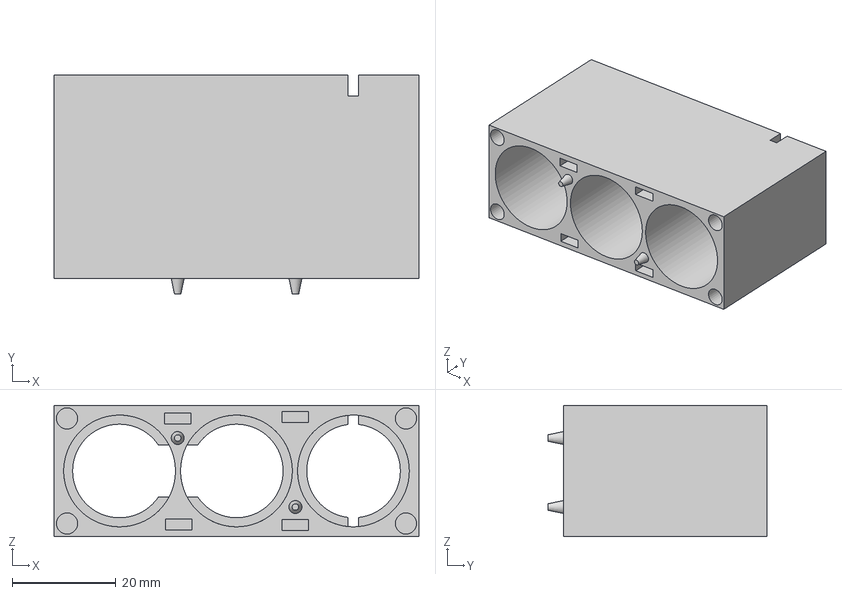
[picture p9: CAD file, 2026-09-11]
3d-model/Documentación 3D/Battery/Case/Lower Case 3S1P Battery/Lower Case 3S1P Battery.3mf
70.2 x 42.2 x 25.2 mm

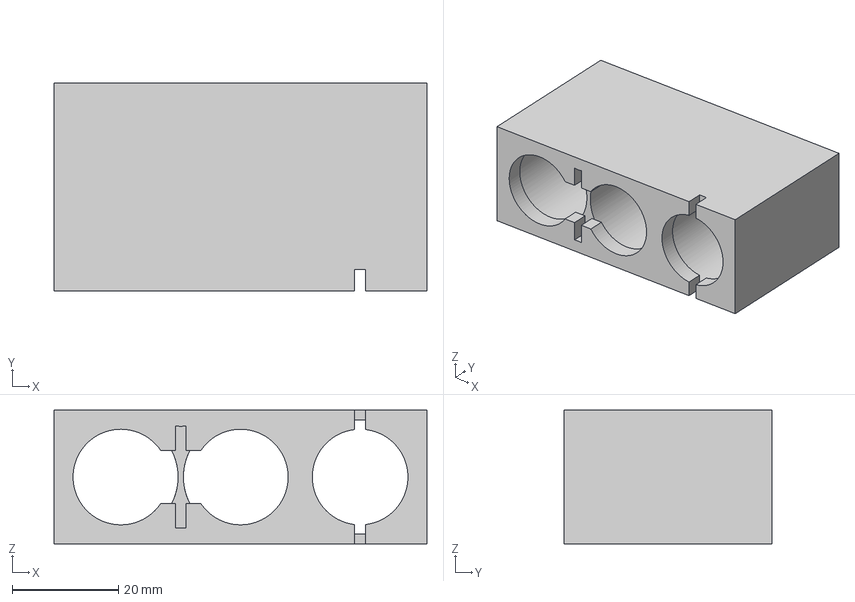
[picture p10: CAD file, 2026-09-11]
3d-model/Documentación 3D/Battery/Case/Upper Case 3S1P Battery/Upper Case 3S1P Battery.3mf
70.2 x 39.2 x 25.2 mm

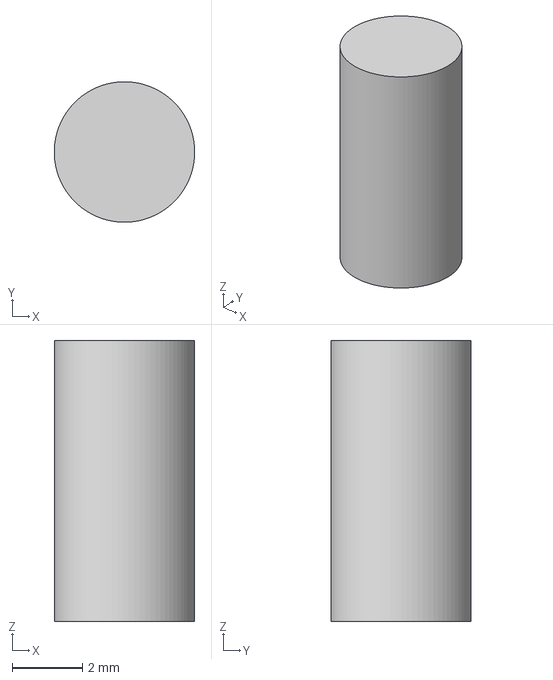
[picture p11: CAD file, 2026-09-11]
3d-model/Documentación 3D/Battery/Fittings/Cylinder (4 parts)/Cylinder1.3mf
4.00 x 4.00 x 8.00 mm

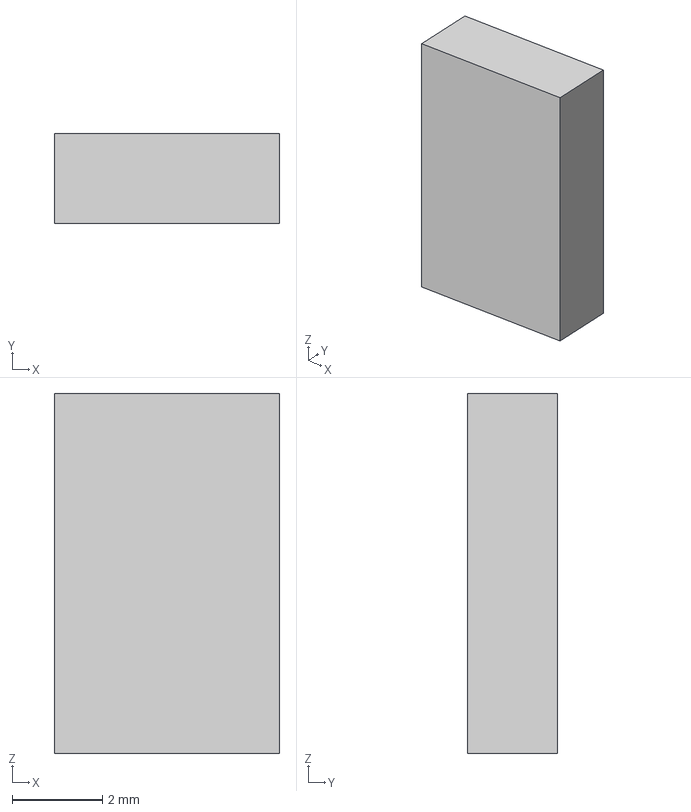
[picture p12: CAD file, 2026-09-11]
3d-model/Documentación 3D/Battery/Fittings/Rectangle (4 parts)/Rectangle1.3mf
5.00 x 2.00 x 8.00 mm

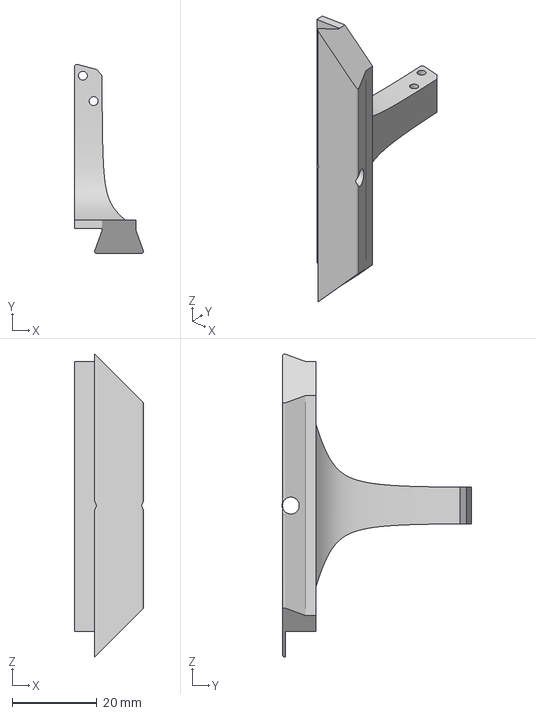
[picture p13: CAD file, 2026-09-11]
3d-model/Documentación 3D/Camera/Camera Support Mount 82.5g/Camera Support Mount 82.5g.3mf
16.3 x 44.7 x 71.5 mm

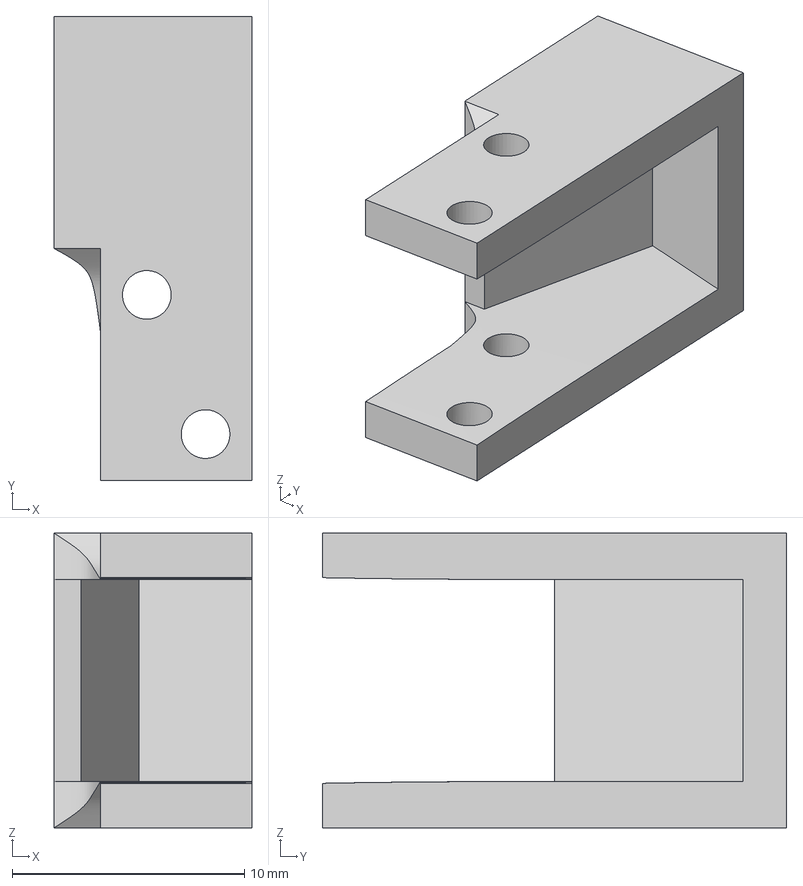
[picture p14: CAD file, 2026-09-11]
3d-model/Documentación 3D/Camera/CameraMount/CameraMount_82.5g.3mf
8.53 x 20.0 x 12.7 mm

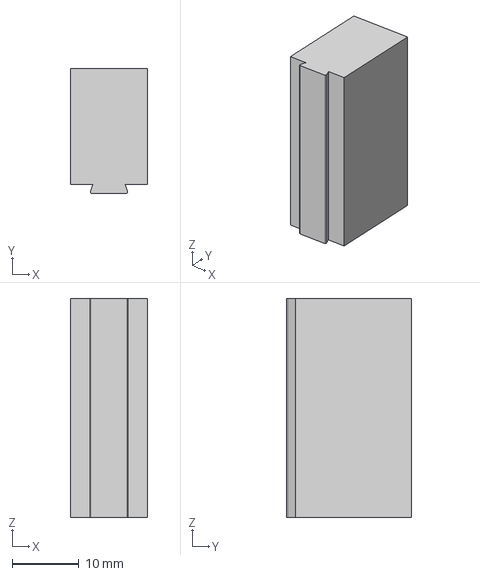
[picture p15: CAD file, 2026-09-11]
3d-model/Documentación 3D/Camera/LowerCameraMount/LowerCameraMount.3mf
11.5 x 18.8 x 32.9 mm

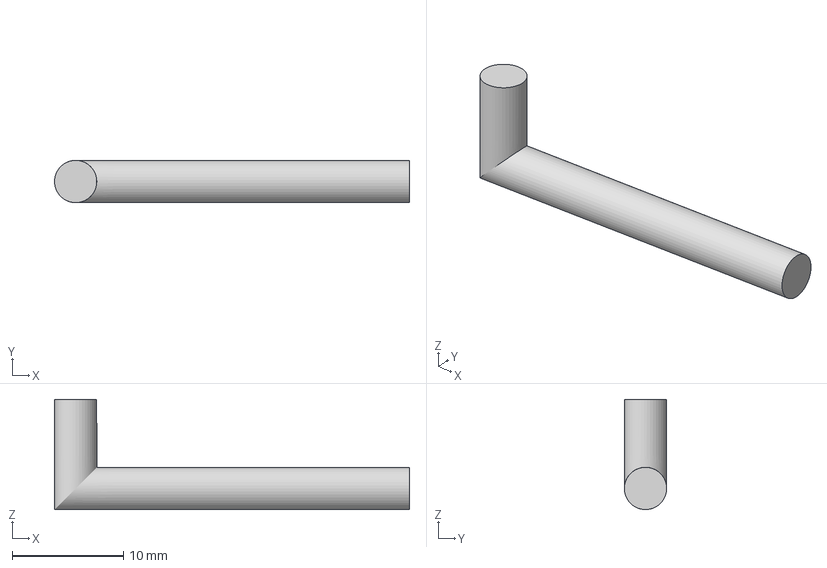
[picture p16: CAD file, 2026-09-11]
3d-model/Documentación 3D/Camera/Pin/Pin.3mf
31.9 x 3.80 x 9.90 mm

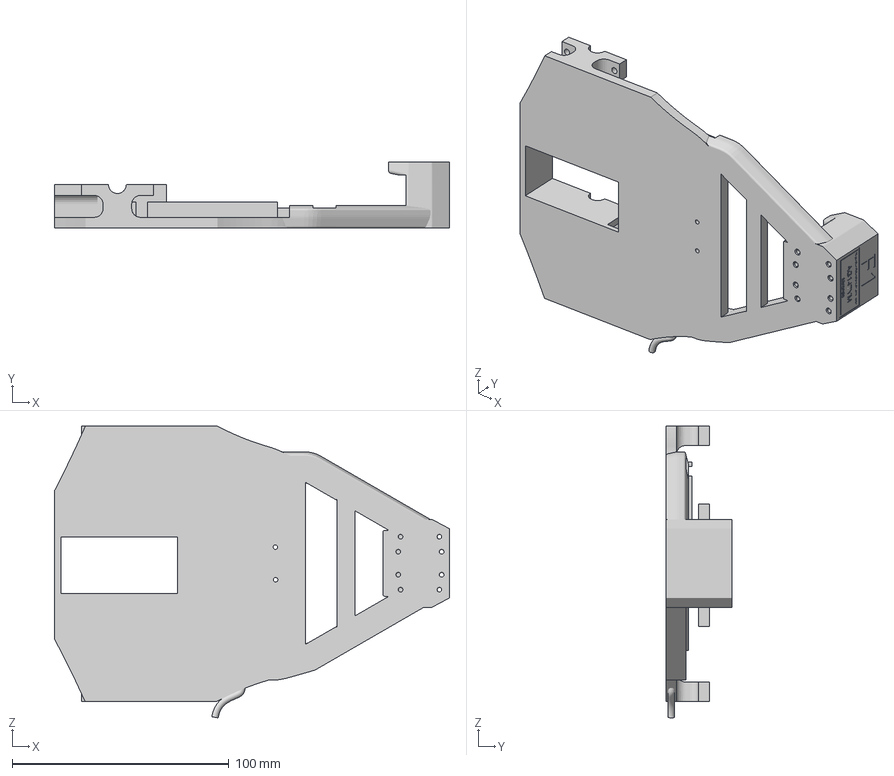
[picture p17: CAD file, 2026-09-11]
3d-model/Documentación 3D/Chassis/Lower Chassis/Lower Chassis.3mf
182.3 x 30.4 x 134.7 mm

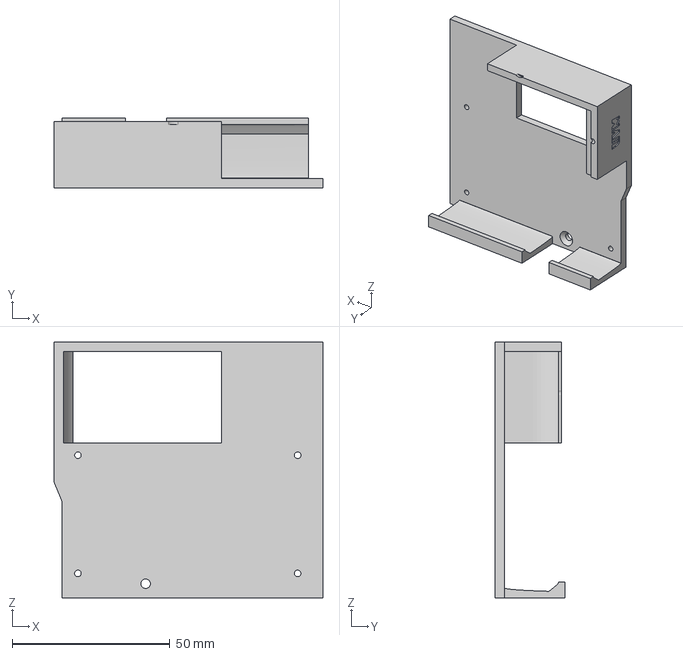
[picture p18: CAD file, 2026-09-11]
3d-model/Documentación 3D/Chassis/Middle Chassis/Middle Chassis.3mf
85.1 x 22.0 x 81.0 mm

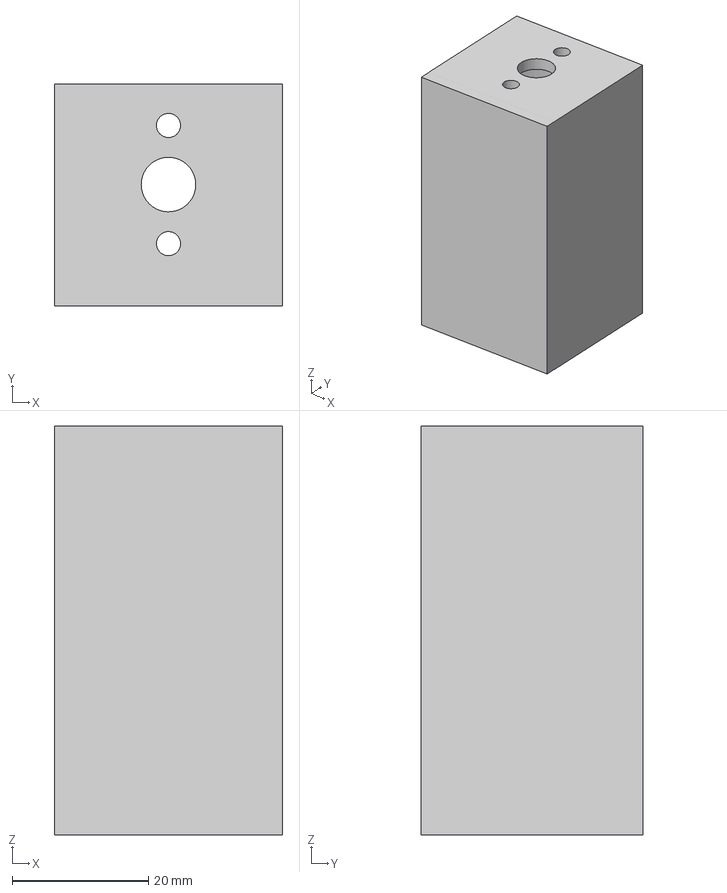
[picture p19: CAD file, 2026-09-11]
3d-model/Documentación 3D/Chassis/MotorChassis/MotorChassis.3mf
33.5 x 32.5 x 60.0 mm

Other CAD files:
3d-model/print-projects/main baseV2.gcode.3mf
3d-model/Documentación 3D/A-Arm/Lower A-Arm Right/Lower A-Arm Right.3mf
3d-model/Documentación 3D/Chassis/Upper Chassis/Upper Chassis.3mf
3d-model/Documentación 3D/Diferrential/Crown Gear 48D Train Type/Crown Gear 48D Train Type.3mf
3d-model/Documentación 3D/Diferrential/Differential Case Cover/Differential Case Cover.3mf
3d-model/Documentación 3D/Diferrential/Left Axle Support/Left Axle Support.3mf
3d-model/Documentación 3D/Diferrential/MotorGear_TrainType/MotorGear_TrainType.3mf
3d-model/Documentación 3D/Diferrential/PlanetGear(2pcs)/PlanetGear.3mf
3d-model/Documentación 3D/Diferrential/PlanetGearAxle/PlanetGearAxle.3mf
3d-model/Documentación 3D/Diferrential/RearGearAndRingLeft/RearGearAndRingLeft.3mf
3d-model/Documentación 3D/Diferrential/RearGearAndRingRight/GearRight/GearRight.3mf
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

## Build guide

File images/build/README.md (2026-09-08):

# Build photos

Workshop and assembly photos: printed parts fresh off the bed, the wiring
before and after tidying, the car on the track, the failures worth remembering.

> **TODO (team):** drop them here with descriptive names
> (`chassis-xvii-printed.jpg`, `wiring-first-version.jpg`, ...). A photo of a
> part that broke is worth more in this repository than a photo of one that did
> not.

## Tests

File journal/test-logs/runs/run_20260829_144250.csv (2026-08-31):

t | state | dir | corners | laps | yaw | target_yaw | head_err | d_inner | d_outer | front | inner_end | corridor | steer | speed | n_pts
0.008 | SIGUE_MURO | 0 | 0 | 0 | -255.62 | 0.0 | -104.38 |  |  | 306.8 |  |  | -10.5 | 30.7 | 62
0.033 | SIGUE_MURO | 0 | 0 | 0 | -255.62 | 0.0 | -104.38 |  |  | 304.8 |  |  | -21.0 | 29.1 | 54
0.058 | SIGUE_MURO | 0 | 0 | 0 | -255.62 | 0.0 | -104.38 |  |  | 308.4 |  |  | -31.6 | 27.7 | 54
0.084 | SIGUE_MURO | 0 | 0 | 0 | -255.62 | 0.0 | -104.38 |  |  | 310.4 |  |  | -42.1 | 26.2 | 57
0.109 | SIGUE_MURO | 0 | 0 | 0 | -255.62 | 0.0 | -104.38 |  |  | 311.5 |  |  | -52.6 | 24.7 | 57
0.134 | SIGUE_MURO | 0 | 0 | 0 | -255.62 | 0.0 | -104.38 |  |  | 310.1 |  |  | -63.1 | 23.1 | 61
0.159 | SIGUE_MURO | 0 | 0 | 0 | -255.62 | 0.0 | -104.38 |  |  | 309.3 |  |  | -73.7 | 22.0 | 60
0.183 | SIGUE_MURO | 0 | 0 | 0 | -255.62 | 0.0 | -104.38 |  |  | 308.8 |  |  | -84.2 | 22.0 | 58
0.208 | SIGUE_MURO | 0 | 0 | 0 | -255.62 | 0.0 | -104.38 |  |  | 308.6 |  |  | -94.7 | 22.0 | 58
0.235 | SIGUE_MURO | 0 | 0 | 0 | -255.62 | 0.0 | -104.38 |  |  | 310.5 |  |  | -100.0 | 22.0 | 63
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

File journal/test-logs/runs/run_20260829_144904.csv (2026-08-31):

t | state | dir | corners | laps | yaw | target_yaw | head_err | d_inner | d_outer | front | inner_end | corridor | steer | speed | n_pts
0.017 | SIGUE_MURO | 0 | 0 | 0 | -733.56 | 0.0 | 29.02 |  |  | 2200.0 |  | 1283.3 | 10.5 | 42.9 | 48
0.042 | SIGUE_MURO | 0 | 0 | 0 | -733.56 | 0.0 | 29.02 |  |  | 2200.0 |  | 1283.3 | 21.0 | 40.7 | 48
0.067 | SIGUE_MURO | 0 | 0 | 0 | -733.56 | 0.0 | 29.91 |  |  | 2200.0 |  | 1258.7 | 31.6 | 38.6 | 48
0.092 | SIGUE_MURO | 0 | 0 | 0 | -733.56 | 0.0 | 30.4 |  |  | 2200.0 |  | 1258.7 | 42.1 | 36.5 | 48
0.117 | SIGUE_MURO | 0 | 0 | 0 | -733.56 | 0.0 | 30.66 |  |  | 2200.0 |  | 1258.7 | 52.6 | 34.3 | 48
0.143 | SIGUE_MURO | 0 | 0 | 0 | -733.56 | 0.0 | 28.38 |  |  | 2200.0 |  | 1187.7 | 63.2 | 32.2 | 48
0.167 | SIGUE_MURO | 0 | 0 | 0 | -733.56 | 0.0 | 27.12 |  |  | 2200.0 |  | 1187.7 | 65.1 | 31.8 | 48
0.193 | SIGUE_MURO | 0 | 0 | 0 | -733.56 | 0.0 | 29.36 |  |  | 2200.0 |  | 1244.9 | 70.5 | 30.7 | 48
0.218 | SIGUE_MURO | 0 | 0 | 0 | -733.56 | 0.0 | 30.59 |  |  | 2200.0 |  | 1244.9 | 73.4 | 30.1 | 48
0.243 | SIGUE_MURO | 0 | 0 | 0 | -733.56 | 0.0 | 31.27 |  |  | 2200.0 |  | 1244.9 | 75.0 | 29.8 | 48
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

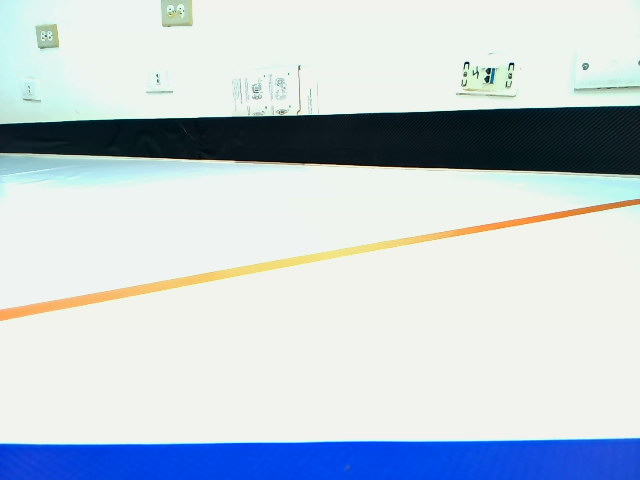
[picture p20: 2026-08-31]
images/test-captures/frames/20260830_144441_pasillo_1000/f035.png

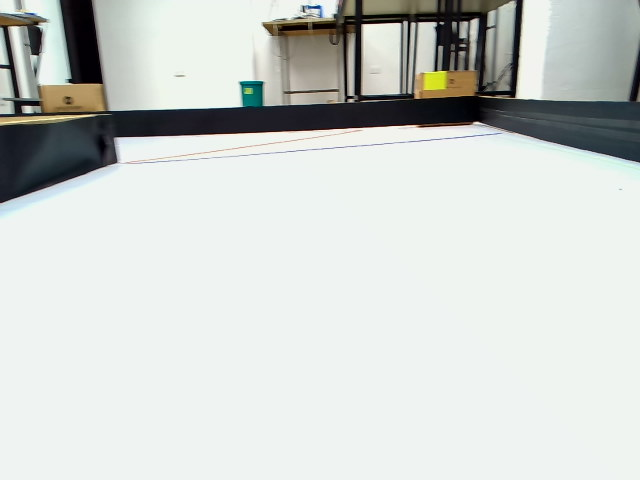
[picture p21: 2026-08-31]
images/test-captures/frames/20260830_144349_pasillo_1000/f011.png

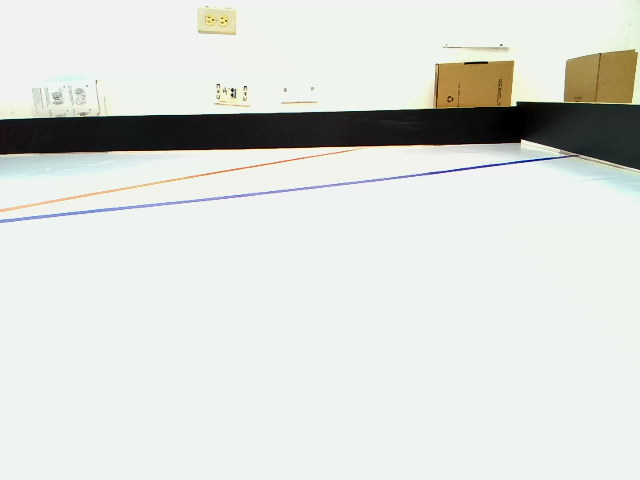
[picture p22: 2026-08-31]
images/test-captures/frames/20260830_144430_pasillo_1000/f058.png

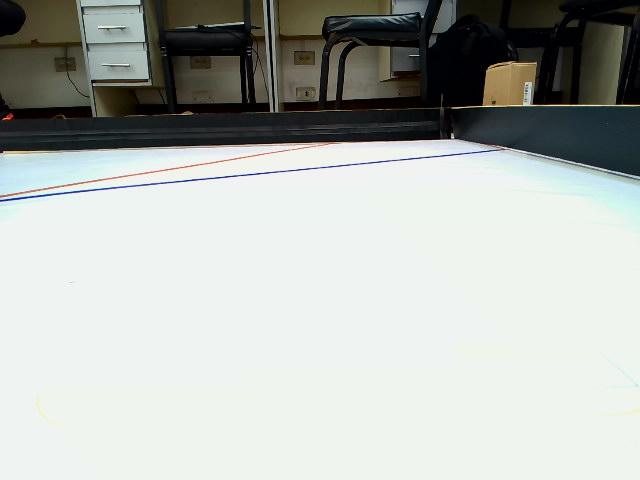
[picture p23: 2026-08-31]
images/test-captures/frames/20260830_144543_pasillo_1000/f021.png

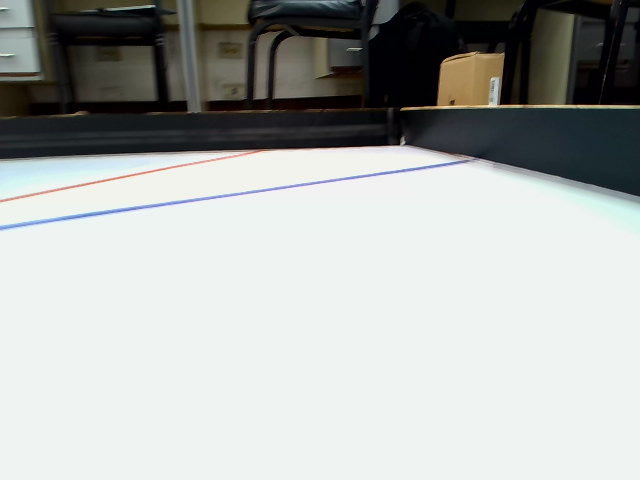
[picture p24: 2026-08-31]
images/test-captures/frames/20260830_144611_pasillo_1000movimiento/f018.png

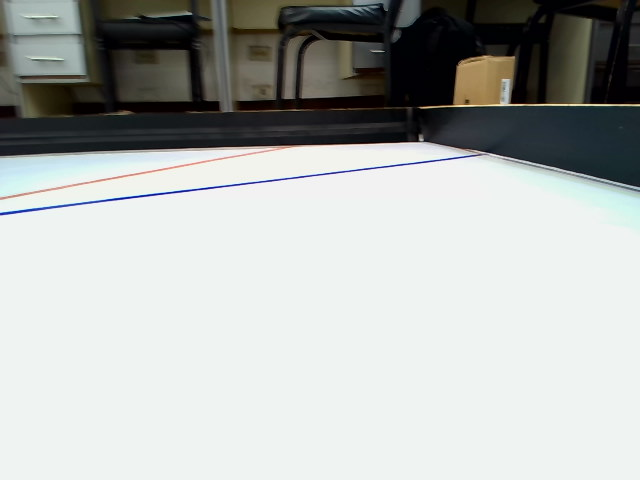
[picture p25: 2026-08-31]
images/test-captures/frames/20260830_144611_pasillo_1000movimiento/f013.png

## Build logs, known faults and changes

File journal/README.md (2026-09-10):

# Journal

How this car was actually built, in the order it happened.

| | |
|---|---|
| [`engineering-journal.md`](engineering-journal.md) | The log: dated entries, decisions, and every failure that taught us something |
| `test-logs/runs/` | CSV logs the car wrote during the 29–30 August test sessions |
| `test-logs/config-agosto.json` | The configuration those runs were made with |
| `prototypes/CONTEXTO-reconizer.md` | The handover document of the previous system: every mistake we had already made by August |
| `prototypes/metodos_navegacion.html` | The comparison of five navigation methods that decided the current one |
| `prototypes/rpi-tools-agosto/` | The simulator and analysis tools from the same period |

## Why the old system is still here

The code of the previous system is not in this folder — it is in
[`../fallback/`](../fallback/), still runnable, because that is where the branch it comes
from put it. What lives here are its documents.

They are in the repository on purpose: they are the reason we know that measuring
the wall by "the lowest black pixel" fails on a shiny wall, that a vote
accumulator with a ceiling saturates in one second, and that a 180° turn measured
by short angular difference never finishes. `CONTEXTO-reconizer.md` is the full
list of mistakes we had already made by August, written the days they happened —
in Spanish, which is the language we work in.

Deleting all of it would have made the repository look cleaner and made the work
look smaller than it was.

## How we keep the journal

One rule: **write it the day it happens.** The dates in the journal match the
commits and the CAD files, because they were written next to them. Anything
reconstructed a month later would be a story, not a record.

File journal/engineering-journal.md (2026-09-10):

# Engineering journal — GreenTech Momboy

WRO 2026, Future Engineers, Venezuela.

This is the log we kept while building the car. It is not a report written
afterwards to look tidy: the entries are dated by what the repository and the
CAD files say, and the failures are in here because they are the part that
taught us something. Where we were wrong, we left it written down.

Two of us build this car, and neither of us built it alone. José took the
obstacle side, Cristian took the Open Challenge, and both of us worked on the
chassis and on every prototype in between. What made that split work was that
we never owned a subsystem privately: the branches are shared, the panel shows
the same telemetry to both, and whoever was at the track that day drove the
decisions of that day.

---

## Phase 1 — Seeing colours (May)

**7 May.** Repository created. We started from the only thing we were sure of:
whatever else the car does, it has to tell red from green and orange from blue,
under whatever light the venue has.

**29 May.** First colour detection working, and the folder structure
reorganised twice in the same day because the first one was already annoying.
Two decisions from this week survived to the final car:

- **Colour is calibrated by clicking on the object in the image**, not by typing
  HSV numbers. And the pixel that is clicked is the one that rules: from the
  patch around it, only pixels that look like it survive. Before that, one click
  on the edge of a pillar mixed in the background and the range grew until the
  mask swallowed the white floor.
- **Five rotating profiles.** Light at home is not light at the venue. Instead
  of one calibration we keep the last five and pick one from the panel.

**2 June.** Vision refactored into modules and a distance test added. The
lesson that pushed this was simple: we could not tell whether a bad run was the
colour, the distance or the steering, because it was all one file.

**3 June.** `chassis v7` in Fusion. Seven versions before the car had ever
driven a lap, and it was already too big.

**5 June.** The floor lines get drawn on screen: the orange and blue lines at
each corner, and the track limits. At this point they were only a drawing. It
took us two more months to understand that those two lines were the most
reliable information the car would ever get.

---

## Phase 2 — Building the thing (June–July)

**16–29 June.** First printed chassis. Motor mount, gear supports, the base,
the covers. The slicer projects from those days are still in
`3d-model/print-projects/` — including a base that took 4 h 25 min to print,
which is a number that shapes your week when a part breaks.

We learned to print for repair, not for elegance: a broken part you can reprint
the same afternoon beats a beautiful one that costs a day.

**Late June — the differential.** The rules forbid a differential-wheeled base,
and they require the driving wheels to be driven together through gearing. We
built a mechanical differential and a single drive motor into the rear axle:
one motor, 2:1 gearing, both wheels turning off the same axle. Ackermann
steering on the front through a rack and pinion driven by the MG996R.

**14–29 July — the chassis stops being a box.** Four full CAD revisions in two
weeks (`WRO CAR`, `vIV`, `V_`, `VII`). This is where the car changed shape
rather than getting details: the electronics deck, the camera mast and the
motor mount became features of one model instead of parts bolted to a plate.

### Why we redesigned instead of improving what we had

The honest reason is that the first chassis was designed around the parts, and
the track does not care about our parts. Once we had driven a few laps we could
list what was actually costing us points, and every item on the list was
geometry:

- **The car did not fit the problem.** The parking bay is 20 cm wide and 1.5
  times the length of the robot. A long car needs a long bay and has to place
  itself in it more precisely. Shortening the car improves parking before a
  single line of code runs.
- **It turned too wide.** In the narrow (600 mm) track configuration the old
  car needed almost the whole corridor to come round a corner. With a 150 mm
  wheelbase and ~26° of lock, the new one turns inside roughly 310 mm of radius.
- **The tail knocked over pillars we had already passed.** With Ackermann
  steering the rear wheel cuts inside the front one. A shorter, narrower car
  sweeps a smaller area — and that area was exactly where the pillar was.
- **The camera moved.** Every distance the software computes comes from two
  numbers: camera height (125 mm) and tilt (7.5°). On the old chassis the mast
  flexed, so those numbers were not constant, so no calibration was ever right.
  On the new one the mast is part of the structure.
- **Weight and print time.** Smaller parts print faster, fail less and leave
  margin under the 1500 g limit.

None of that would have been visible from a drawing. We had to build the big
one first.

---

## Phase 3 — Two brains (August)

**20 August.** ESP32 firmware in the repository. The architecture stops being
"the Pi does everything" and becomes two controllers with one job each: the Pi
sees and decides, the ESP32 moves and protects.

We took the Wi-Fi out of the ESP32 completely. Not because of the radio rule
alone — although the rules do forbid wireless while the vehicle runs — but
because two things that can give orders is one thing too many. The ESP32 obeys
binary frames over a cable, and if the Pi goes quiet for 300 ms it stops the car
by itself. That failsafe is the reason there is a microcontroller in the middle
at all.

**28–29 August.** Navigation rebuilt, obstacle avoidance implemented, and the
MPU-6050 and the TCS34725 finally reconnected and read from the ESP32.

**The sensors that "were not there".** The ESP32 probed the I2C bus in `setup()`,
right after `Wire.begin()` — before the sensors had woken up, and while the
motor start-up was pulling the rail down. It declared both absent, for the whole
run, every run. The fix is three lines and one habit: wait 250 ms, retry every
3 s while one is missing, and put a manual retry button in the panel.
The general lesson we wrote on the wall: *any hardware auto-detection needs an
automatic retry, a manual retry, and somewhere you can see whether it is there.*

**29–30 August.** Test runs with logging. The CSV files in `test-logs/runs/`
and the frame sequences in `../images/test-captures/` come from these sessions.
Being able to replay a run on a laptop, frame by frame, changed how we work:
from that week on, no fix was accepted because it sounded right, only because
the recorded run improved.

**30–31 August.** Wall, navigation and orientation corrections. Colour
calibration and obstacle parameters. Corner handling reworked.

---

## Phase 4 — The four bugs that were really one (September)

Everything in this phase came from the same root cause: **the car knew where it
was pointing, but not which straight it was on.**

**31 Aug – 2 Sept — the corner loop.** At the corner the car would circle
inside it, as if the gap were the road. And for any free-space navigator, it
*is*: when the inner wall ends it leaves an enormous gap of white floor, the car
drives into it, sees another gap from its new position, and repeats. In a real
capture the corridor measured 1064 mm of clear road at the exact moment the car
had to turn. No threshold fixes that — the vision was answering the wrong
question. Three pieces fixed it: the floor line triggers the corner by itself,
the 90° turn runs committed so the camera cannot redirect it, and a corner that
has been turned cannot trigger again.

**2 Sept — the phantom turn.** Crossing the orange line, the car turned
correctly; a while later the blue line arrived and triggered *another* 90° turn,
sometimes the wrong way and between pillars. The code treated each line
separately, so a late blue line looked like the first line of a new corner. Now
a corner **opens** with its first line and waits for the other to **close** it —
the second line can never open a new one. Tested against four corners in a row
losing the blue line every time: the count still comes out at four.

**2–3 Sept — the blue line the sensor never saw.** The TCS34725 counted oranges
and never a blue. Two causes, and the second was the one that bit: the stored
profile had a clear-channel minimum taken from a very bright white, but a
coloured line *absorbs* light and returns much less — the reading was thrown
away before the colour was even looked at. And the absolute thresholds had a
ridiculous margin: blue beat white by three units in its own channel. We
switched the discriminator to the difference between the blue and red channels
(+37 on blue against ~0 on white) and lowered the clear minimum. Sampling a line
now lowers that minimum automatically if it has to.

**5–6 Sept — the side of the pass, and the corner that ate the pillars.**
Passing a pillar on the wrong side ends the round, so this one got a rule of its
own: the side comes from the colour and is never negotiable; only the distance
is clipped. In the same days we added the colour-corner mode, where only one
colour counts and the turn **gives way the instant a pillar appears** —
because the forced 90° turn was knocking over the pillars sitting at the exit of
the corner.

**7 Sept — re-anchoring the heading.** The last one, and our favourite, because
the symptom made no sense: the car crossed the line, turned correctly, and then
kept turning the *other* way into the wall. The heading reference only advanced
90° when the code registered a corner. If the colour sensor missed the line, the
car took the corner physically — on white space alone — while the code still
believed the straight was the previous one. The gyro was then dutifully pulling
the car back towards a straight that no longer existed. Now, if the car has been
turned by a corner-sized angle for long enough, in the direction of the round,
it adopts the new straight: that was a corner nobody registered.

**8 Sept — the button.** Until this week the car was armed from the web panel,
which cannot be how a competition round starts: the rules want one action on a
robot already placed on the track, and no wireless while it runs. So the round
now starts with **one push button on GPIO 13**, working like a stopwatch — press
to arm and go, press again to stop — plus a status LED on GPIO 2.

Two decisions inside that are worth more than the button itself. First, the
press travels to the Pi as a **level, not a counter**: a counter would store
presses, and a serial glitch with an undelivered press could start the car by
itself on reconnect. With a level, what is lost is simply not executed. Second,
when the car is armed a press can only mean *stop*, so the **ESP32 latches the
cut locally** and the motor dies on the next 10 ms tick — no round trip over
serial, and it works even if the Pi is hung shouting "forward". The self-test
suite went from 295 to 323 checks with it.

**8 Sept — one repository instead of four branches.** Chassis **WRO CAR XVII**
closed as final, and the repository unified: the pilot and the button branch
merged, the documentation written, and the code split into `main/` (what we
race) and `fallback/` (the system before it), each runnable on its own. The point is being able to fall back to a
known-good program in the pits by changing which `main.py` we launch, instead of
reverse-engineering a git revert under pressure.

---

## Our coach

Our tutor and coach is **Msc. Edgardo Paolini**.

The rules are explicit that a coach may not build or program the robot, and ours
did not. What our coach did do was harder to write in a commit: made sure a
track existed to test on, asked what we had *measured* every time we said
something "worked", made us stop and document at points where we would happily
have kept hacking, and kept two teenagers with very different working hours
turning up to the same sessions. The bug list in this journal exists because we
were asked, repeatedly, how we knew.

## What working as two people actually looked like

- **Split by challenge, not by layer.** José on obstacle detection, Cristian on
  the Open Challenge. It meant each of us owned a whole vertical slice — vision,
  decision and driving — for one round, and could debug it end to end without
  waiting for the other.
- **Branches, and merging them on purpose.** `main` for what works, working
  branches for what does not yet. The merge is where we reviewed each other, and
  it caught things a lone author never sees.
- **The panel is the shared language.** Everything is adjustable while the car
  runs, and everything is on screen. Two people who can both see the same
  telemetry argue about the car, not about opinions.
- **Everything testable runs without the car.** 323 checks that need no camera
  and no hardware. There is one car and two of us: whoever does not have it can
  still work.

## What we would tell the next team

1. **A physical fact beats a clever inference.** The floor line under the car
   fixed a problem that months of vision tuning did not.
2. **Instrument first, tune second.** Every fix in September came from a
   recorded run we could replay, not from reading code.
3. **Redesign the mechanics when the mechanics are the problem.** We spent
   weeks compensating in software for a chassis that was too long. The compact
   chassis solved it in one afternoon of CAD.
4. **A failure that is safe beats a failure that is silent.** When the wall is
   ambiguous, the code marks it "unknown" and ignores it, instead of guessing.
5. **Write it down the day it happens.** Everything above came out of notes and
   commit messages written the same day. Reconstructed a month later, none of it
   would have been true.

## What's next

- The parallel parking manoeuvre and the rear camera (the slot is reserved, the
  code is not written).
- Measure the power budget properly, and the finished car's weight.
- Take the required photos and record both videos.

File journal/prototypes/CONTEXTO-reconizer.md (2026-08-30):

# Contexto del proyecto — Carro WRO 2026 Futuros Ingenieros

Documento de traspaso. Resume de dónde viene el proyecto, qué decisiones se
tomaron y por qué, cómo funciona el código, y qué se aprendió a base de romperlo.
No es un reglamento: si encuentras una manera mejor de hacer algo, hazla.

---

## 1. El proyecto

Equipo **GreenTech Momboy**, categoría **Futuros Ingenieros** de la WRO Venezuela
2026 (14-22 años, 2-3 estudiantes). Competencia a primeros de septiembre.

El reto: un carro autónomo que da vueltas a una pista cuadrada. Tapete de
3200×3200 mm, pista interior de 3000×3000, **piso blanco**, muros exteriores e
interiores de **100 mm de alto y negros por dentro**. En el reto de obstáculos
hay **7 señales verdes y 7 rojas de 5×5×10 cm** y una zona de estacionamiento
magenta. En el suelo hay una **línea naranja y una azul en cada esquina**.
Robot máximo 30×20×30 cm, hardware y software libres.

**Importante para la navegación:** el ancho del carril **varía** de una pista a
otra en competencia abierta. Nada puede depender de un ancho fijo.

### Hardware

```
Raspberry Pi 5 (8 GB)  →  ESP32  →  puente H  →  motor DC
                            ↓
                          servo MG996R (dirección Ackermann)
```

- **Cámara USB 2.0 WN-L1812.K56R** (sensor IMX179), única fuente de percepción
  del entorno. En el flex pone `WN-L1812.K56RA 32PIN`.
- **MPU6050** y **TCS34725**: conectados al **ESP32** por I2C, con sus pines INT
  cableados. El código admite pasarlos al I2C de la Pi cambiando una palabra.
- El ESP32 está en medio **como medida de seguridad**: si la Pi se cuelga, él
  para el carro.

### Entorno de desarrollo

Se desarrolla **entre el PC (Windows 11) y la Raspberry (Raspbian)**, así que
todo el código tiene que funcionar en los dos sin cambios. Python 3.11 (por
OpenCV y compañía) y C++ para el ESP32.

Repo del equipo:
`OR\Future-Engineers---GreenTech-Momboy\code\raspberry\reconizer`

---

## 2. Ideas y decisiones del equipo

Esto es lo que se pidió y por qué. Son las que mandan.

**Calibración de color rápida.** Detección por color en HSV buscando respuesta
rápida, pero sabiendo que el HSV hay que recalibrarlo según la luz. De ahí:
un archivo con las **últimas 5 calibraciones**, un programa con **sliders y
además casillas para escribir el valor exacto**, y **clic sobre el objeto** en
la imagen para tomar su color. El programa principal elige entre las 5.

**Reconocimiento de objetos.** Partiendo de un enfoque previo donde "las manchas
que se tocan son un mismo objeto", se pidió mejorarlo y que los parámetros
fueran ajustables con slider y escribiendo.

**Medir el muro por columnas, no por un píxel.** La propuesta original fue medir
el píxel negro en la mitad de la cámara y trazar por dónde pasan las ruedas
(porque **la cámara no ve las ruedas**). Eso se generalizó a medir en todas las
columnas.

**Arquitectura del enlace.** Se pidió expresamente: datos muy ligeros, array de
bytes con protección contra ruido, FreeRTOS en el ESP32 y la respuesta de los
motores lo más rápida posible. Y una **última línea de defensa** que compruebe
siempre que al servo no le llegue una orden fuera de límite, para no romper
piezas.

**Sensores al ESP32, procesados donde toque.** La idea fue que el ESP32 mande
datos ligeros a la Pi cuando los sensores detecten cambios, y que si los datos
son muchos los procese la Raspberry. Con compatibilidad para moverlos a la Pi
en el futuro.

**Vueltas y media vuelta.** 3 vueltas de ida y 3 de vuelta, con el número
configurable desde la interfaz de monitoreo. La media vuelta con dos maniobras
elegibles (en recta de tres tiempos, o aprovechando el hueco de la esquina).

**Esquivar pilares.** Rojo y verde, con interruptor para activar y desactivar
desde la interfaz.

**Método de navegación favorito del equipo:** buscar el ángulo entre obstáculos
por donde sea posible pasar, dejando los obstáculos fuera de los bordes por
donde pasan las ruedas, y teniendo en cuenta el siguiente obstáculo.

**Convención de sentido (la del equipo):** pared externa a la **izquierda** =
antihorario; pared externa a la **derecha** = horario. *(Ojo: esto es al revés
de la derivación geométrica habitual — en un anillo, con la externa a la
izquierda el centro queda a tu derecha, que sería horario. Se adoptó la
convención del equipo porque es la que leen en pantalla y porque lo que de
verdad manda el comportamiento es `lado_externo`, no la etiqueta. Si algún día
cuadra mejor al revés, se cambia en un sitio.)*

**Qué funciona mejor hoy, según las pruebas en pista:** la navegación
**centrada**, con la opción de **girar cuando la pared interna deja de verse**.
Es la combinación más rápida y fiable de las probadas.

**Preferencia de interfaz:** todo ajustable en caliente desde el monitoreo, sin
recompilar ni reiniciar. La Pi crea su propio WiFi y retransmite lo que ve,
incluidos los objetos reconocidos, en `carrito.local`.

---

## 3. Arquitectura

```
reconizer/
├── main.py                  arranca todo; --simulado, --imagen, --vmax, --sin-panel
├── config/
│   ├── colors.json          5 perfiles de color rotativos + cuál está activo
│   └── robot.json           puerto, límites, ganancias, red, vueltas, obstáculos
├── src/
│   ├── color_config.py      perfiles de color, guardado atómico, migración
│   ├── camera.py            cámara USB igual en Windows y Linux
│   ├── vision.py            máscaras HSV y detección de objetos
│   ├── protocolo.py         trama binaria hacia el ESP32
│   ├── enlace.py            hilo serie, autodetección de puerto, telemetría
│   ├── sensores.py          rumbo y color: del ESP32, de la Pi, o de ninguno
│   ├── imu.py               MPU6050 por I2C de la Pi (alternativa)
│   ├── navegacion.py        perfil del muro, estrategias, esquinas, escape, media vuelta
│   ├── obstaculos.py        esquiva de pilares rojos y verdes
│   ├── vueltas.py           contador de vueltas fusionando 3 fuentes
│   ├── robot.py             el núcleo que une todo
│   ├── robot_config.py      robot.json
│   └── servidor.py          carrito.local:8080 — vídeo MJPEG + control
├── tools/
│   ├── calibrador.py        interfaz de calibración HSV
│   ├── panel.py             panel de escritorio (Tkinter)
│   ├── widgets.py           slider+casilla compartidos
│   ├── selftest.py          51 pruebas de visión, sin cámara
│   ├── selftest_robot.py    224 pruebas del sistema, sin carro
│   ├── test_firmware.cpp    59 pruebas del ESP32, con g++, sin ESP32
│   └── carrito_wifi.sh      AP, mDNS, UART, I2C, servicio
├── docs/
│   ├── CONTEXTO.md          este archivo
│   └── metodos_navegacion.html  análisis de 5 métodos de navegación
└── firmware/esp32_carro/
    ├── esp32_carro.ino      firmware (sin WiFi)
    ├── protocolo.h          gemelo en C++ de protocolo.py
    ├── seguridad.h          límites del servo y del motor (C++ puro, testeable)
    ├── lineas.h             clasificador naranja/azul (C++ puro, testeable)
    └── sensores_i2c.h       MPU6050 y TCS34725 autodetectados
```

**Regla de diseño que ha funcionado:** todo lo que puede romper hardware o
contar mal vive en C++ puro o Python puro y **se prueba sin el carro**. Por eso
hay 334 pruebas que corren en cualquier PC.

---

## 4. Cómo funciona

### 4.1 Visión y calibración

`colors.json` guarda hasta 5 perfiles; el más nuevo va primero y el sexto
descarta el más viejo. Escritura atómica (tmp + rename); si el JSON se corrompe
se respalda como `.bak` y se regenera. Un perfil guardado antes de que existiera
un color nuevo lo hereda con valores por defecto sin pisar lo calibrado.

Colores definidos: `rojo`, `verde`, `negro` (en uso), `magenta`, `naranja`,
`azul` (listos). El rojo lleva **dos rangos HSV** porque el tono se envuelve en
H=0/179.

**Detección de objetos** (`vision.py`): una conversión a HSV por frame, máscara
multi-rango, `MORPH_OPEN` (mata motas) + `MORPH_CLOSE` (tapa el brillo del
centro del pilar), y luego la parte importante — **fusión por hueco**: se dilata
una *copia* de la máscara y se etiqueta sobre esa copia, pero el área, la caja y
el centro se remiden sobre la máscara **original**. Así un pilar partido en dos
por un reflejo vuelve a ser un objeto sin que la caja se infle. Filtros: área,
**llenado** (área/caja — un pilar sólido da 0.95, el ruido disperso 0.2; es el
que más basura quita), aspecto, ancho/alto mínimos y una **ROI vertical** para
no procesar por encima del muro.

**Toma de color por clic**: el píxel exacto que se clica manda; del parche solo
sobreviven los píxeles parecidos a él. Sin eso, un clic en el borde del objeto
mezclaba fondo y el rango se comía el piso blanco. Si la muestra es acromática
(negro, gris, blanco) el tono se abre a 0-179 y mandan S y V — por eso el mismo
clic sirve para calibrar el negro de las paredes.

### 4.2 El perfil del muro (base de toda la navegación)

Para cada columna de la imagen se busca el **píxel negro más bajo**: ahí el muro
toca el suelo. Cuanto más abajo, más cerca. Sale un perfil de distancia de ancho
completo, como un LIDAR pobre. Es un `argmax` sobre la máscara del revés: una
pasada vectorizada, ~0.3 ms en 640×480.

Del perfil salen: `izq`, `der` (media de las bandas laterales), `pasillo`
(percentil 15 entre las líneas de las ruedas — percentil y no mínimo, para que
una columna con ruido no frene el carro), **`cobertura_izq`/`cobertura_der`**
(qué fracción de cada banda *ve* muro, distinto de a qué distancia está),
**bordes** (escalones del perfil) y **huecos**.

### 4.3 Estrategias de navegación (mezclables con pesos)

- **centrado** — compara el espacio libre izquierda/derecha y gira hacia el
  despejado con un PD. La más tolerante a calibración imperfecta. **La que mejor
  funciona hoy.**
- **pared** — mantiene la pared externa a distancia fija con un PD. En `auto`
  deduce sola cuál es la externa.
- **hueco** — la idea del equipo: tramos por los que el carro **cabe de verdad**,
  contando el ancho de las ruedas a la distancia del obstáculo que delimita el
  hueco. La conversión usa perspectiva de plano de suelo (un ancho real fijo se
  ve proporcional a `y − horizonte`) anclada en las líneas de las ruedas, así que
  no hace falta patrón de calibración. La puntuación incluye el **siguiente
  obstáculo**: si detrás de la boca hay otra cosa, la parte profunda del tramo
  tiene poco espacio libre y el candidato pierde puntos.

Los pesos se suman y se ven los aportes de cada una en la telemetría.
`mezcla` es la fuente de verdad; `estrategia` solo actúa si todos los pesos son 0.

### 4.4 Máquina de estados

`RECTO → PRE_GIRO → GIRO → RECTO`, con `ESCAPE` y `MEDIA_VUELTA` por encima.

- **PRE_GIRO** existe para frenar *antes* de doblar y para dejar que las ruedas
  traseras pasen la esquina interna (`retardo_giro_ms`).
- **GIRO** usa `dir_giro_abierto` (65 %, no a tope) y, si hay hueco pasable,
  apunta a él (`giro_diagonal`), que es lo que traza la diagonal a la siguiente
  pared externa.
- **ESCAPE** cuando el pasillo se cierra por debajo de `parar_bajo`.

### 4.5 Anticipación (el problema de la inercia)

Dos capas:
1. **Envolvente de velocidad** por distancia.
2. **Tiempo hasta el muro**: se mide la *velocidad de cierre* del pasillo y se
   calcula cuántos segundos faltan. Si bajan de `ttc_min` se frena aunque la
   distancia parezca aceptable. Esto es lo que hace que llegue a la esquina ya
   frenado, y es el slider que más se toca en pista.

### 4.6 Identificación de paredes y sentido

El muro **externo se ve casi siempre**; el **interno desaparece en cada esquina**.
Se lleva una **media móvil de "esta banda ve muro"** por lado; la de mayor
presencia es la externa. Votan además: los giros hechos, las desapariciones de
muro y el orden de las líneas del suelo. Se puede **forzar a mano** desde la
interfaz (auto / horario / antihorario).

Tras la media vuelta las presencias se **intercambian** y el estimador queda
**bloqueado unos segundos**.

### 4.7 Disparo de esquina

`DetectorEsquinaInterna` avisa cuando una banda que **tenía** muro deja de
tenerlo, en cualquiera de los dos lados. **No necesita saber el sentido**, así
que gira bien desde la primera esquina. Cuenta como "ya no hay muro" tanto que
la banda se quede sin píxeles como que lo que se ve ahí esté tan lejos que ya
sea la pared de enfrente (`interno_lejos`), porque según el ángulo con el que
llegues pasa una cosa o la otra.

### 4.8 Escape

Retroceso **comprometido**: se calcula cuánto espacio falta y se retrocede al
menos ese tiempo (`escape_atras_min_ms` + extra escalado por el déficit), sin
reevaluar a mitad. Se abandona solo si el espacio de delante no mejora nada en
`escape_atascado_ms`, que es la firma de tener algo pegado detrás; entonces se
prueba el giro hacia adelante. La marcha atrás lleva la dirección **hacia** el
muro, para que el morro se separe (como al salir de un aparcamiento).

### 4.9 Autocalibración del carril

En recta, con poca dirección y el frente despejado, la **suma del espacio libre
de las dos bandas es casi constante** y no depende de por dónde vayas dentro del
carril: esa suma *es* el ancho del carril en unidades del perfil. De ahí se
derivan `parar_bajo`, `girar_bajo` y `frenar_bajo`, acotados. Es lo que permite
competir en pistas de ancho distinto sin tocar nada.

### 4.10 Vueltas

Tres fuentes: **cámara** (líneas del suelo), **TCS34725** (por contacto) y los
**giros de 90°** contados por la navegación. Una esquina se da por buena cuando
se completa un par de líneas o cuando termina un giro, y hay un **periodo
refractario** de 3 s durante el cual no se admite otra venga de donde venga.
Cuatro esquinas = una vuelta. Al llegar al objetivo pide la media vuelta y
cuenta otras tantas en sentido contrario.

### 4.11 Esquiva de pilares

Rojo → se pasa por su **derecha**; verde → por su **izquierda**. Del más cercano
se calcula un objetivo a su lado correcto, separado medio ancho de carro (escalado
por perspectiva) más margen. El objetivo se **recorta al pasillo libre**: sin eso,
esquivar un pilar pegado a la pared manda el carro contra la pared. El peso sube
según se acerca (`activar_desde` → `mandar_desde`).

**Matiz importante:** *pasar por la derecha del pilar* no es *girar a la derecha*.
Si el pilar está a la izquierda del carro, el punto por el que hay que pasar puede
quedar a la izquierda del centro.

### 4.12 Enlace Pi ↔ ESP32

Trama de 11 bytes: `A5 5A | LEN | TIPO | payload | CRC8`.

`vel` y `dir` viajan en **porcentaje con signo**, nunca en unidades de hardware:
la Pi no sabe nada de grados de servo ni de PWM, así que **no existe forma de
expresar un ángulo imposible en el protocolo**. El mapeo lo hace el firmware,
que es quien conoce los límites físicos.

`protocolo.py` y `protocolo.h` son gemelos, y `selftest_robot.py` cruza vectores
generados por el binario de C++ contra los de Python: si alguien toca uno solo,
la prueba falla.

Autodetección de puerto: `/dev/serial0`, `ttyAMA0`, `ttyUSB*`, `ttyACM*`, `COM*`.
Se manda un PING y se espera respuesta. El firmware escucha **las dos bocas** (USB
y GPIO16/17) y contesta por la que recibió la última trama válida.

### 4.13 Seguridad, en orden de quién reacciona antes

1. El navegador frena cuando ve que el pasillo se cierra.
2. Si el lazo de visión se atasca >250 ms, el enlace manda velocidad 0. **No
   repite la última orden**: repetir una orden vieja es exactamente lo que hace
   que un carro siga a fondo contra la pared.
3. Si el serial se calla >300 ms, el ESP32 corta el motor y **centra el servo**.
4. Si la tarea de control del ESP32 se cuelga >200 ms, una tarea vigilante de
   prioridad máxima corta el PWM directamente sobre el hardware.
5. Ctrl+C, cerrar la ventana o perder la cámara mandan parada de emergencia.

**Límites del servo**: `SERVO_TOPE_MIN=50` y `SERVO_TOPE_MAX=145` son constantes
de compilación. La configuración en caliente solo puede *estrechar* el rango. El
límite se aplica cuatro veces. Además hay límite de grados/segundo, y el motor
**nunca invierte sin pasar por cero y esperar 150 ms**.

---

## 5. Errores que ya se cometieron (y cómo se detectaron)

Todos salieron de pruebas o de mirar capturas, no de leer el código. Vale la pena
conocerlos porque el patrón se repite.

**Sensores I2C que no aparecían.** El ESP32 los sondeaba en `setup()` justo
después de `Wire.begin()`, antes de que el MPU y el TCS despertaran (y comparten
alimentación con el motor, que hunde el riel al arrancar). Los daba por ausentes
para siempre. **Solución:** esperar 250 ms antes del primer sondeo, **reintentar
solo cada 3 s** mientras falte alguno, y un botón de reintento manual en la
interfaz. *Lección general: cualquier autodetección de hardware necesita
reintento automático + manual + un sitio donde ver si está o no.*

**Acumulador de votos que se saturaba.** El estimador de sentido votaba en cada
frame contra un acumulador con tope ±6: se saturaba en un segundo y luego hacían
falta 48 frames en contra para moverlo. Decía siempre "horario" y **deshacía la
media vuelta**. *Lección: no acumular votos con tope en un bucle que corre a 30
Hz; usar una media móvil que se pueda corregir sola.*

**Medir 180° con la diferencia angular corta.** Se envuelve: al pasar de 180
empieza a bajar y la media vuelta no terminaba nunca. *Hay que acumular el giro
paso a paso.*

**Pausa de inversión del motor que nunca saltaba.** Comparaba contra el PWM
instantáneo; en cuanto llegaba a 0 la condición dejaba de cumplirse y saltaba a
reversa. *Hay que comparar contra el último sentido real de giro y usar reloj.*

**Lector de tramas de una pasada.** Si llegaba una trama truncada, se tragaba los
bytes de la siguiente creyendo que eran su payload y perdía las dos. *Ahora
acumula en buffer y reescanea un byte hacia adelante cuando el CRC falla.*

**Clic de calibración que pisaba el borde.** El parche mezclaba objeto y fondo y
el rango salía tan abierto que la máscara se comía el piso.

**Deduplicación de esquinas demasiado corta.** 2,2 s solo tapaba lo muy seguido;
al cruzar una esquina llegan naranja, azul, a veces naranja otra vez y además el
giro → contaba 3. *Refractario de verdad + dominancia entre las dos líneas.*

**Escape que alternaba adelante/atrás cada 700 ms.** Con el muro encima, 700 ms
de marcha atrás no dan para nada: el carro iba y venía sin ganar sitio hasta
chocar. *Compromiso mínimo escalado por el déficit.*

---

## 6. Estado actual

**Funciona bien:** navegación centrada + giro por desaparición del muro interno
(lo más rápido y fiable), calibración de color, enlace y telemetría, seguridad a
todos los niveles, esquiva de pilares (validada sobre foto real con el perfil
`Prueba1` del equipo).

**Probado en banco, pendiente de pista:** el arreglo de la media vuelta, el
retroceso comprometido, el refractario del conteo de esquinas, el reintento de
sensores, la esquiva en movimiento.

**Sin montar todavía:** MPU6050 y TCS34725 físicamente (el código los espera y
funciona sin ellos).

**Pruebas:** 334 en total.
```bash
python3 tools/selftest.py           # 51, visión, sin cámara
python3 tools/selftest_robot.py     # 224, sistema, sin carro
g++ -std=c++17 -O2 -I firmware/esp32_carro tools/test_firmware.cpp -o /tmp/tfw && /tmp/tfw
```

**Cómo probar sin hardware:**
```bash
python3 main.py --simulado --imagen capturas/loquesea.png
```

---

## 7. Ideas pendientes

Del análisis en `docs/metodos_navegacion.html` (5 métodos, 3 analizados a fondo):

1. **Medir primero** con lo que hay: dar vueltas con el centrado y mirar en
   `carrito.local` el ancho de carril autocalibrado, los segundos hasta el muro
   en las esquinas y cuántas veces entra en escape.
2. **Mezcla por confianza** — que cada estrategia diga cuánto se fía de sí misma
   y su peso se multiplique por eso. Barato y reversible. Ataca directamente el
   "la pared gira tarde": en la esquina no tiene pared que seguir pero sigue
   opinando igual de fuerte.
3. **Arcos de dirección** — evaluar la curva que el carro puede recorrer de
   verdad (radio ≈ batalla/tan(ángulo)) en vez de un punto. Lo que más mejoraría
   y lo que más cuesta; hay que medir la batalla y el ángulo real de las ruedas.
4. Vista de pájaro por homografía y VFH+ quedaron descartados por ahora.

Además: estacionamiento en la zona magenta, y afinar la esquiva con obstáculos
reales en pista.

---

## 8. Notas prácticas

- **Congela la exposición y el balance de blancos** de la cámara antes de
  calibrar. Si siguen en automático, al girar hacia una pared blanca la cámara
  reajusta y la calibración HSV deja de valer.
- **Calibra el giroscopio con el carro quieto** cada vez que enciendas.
- Al subir firmware nuevo, súbelo **antes** de correr `main.py` (si cambió el
  protocolo, el firmware viejo se queda en failsafe).
- Primera prueba del día: `python3 main.py --vmax 70` con las ruedas al aire para
  confirmar el sentido de giro. Si va al revés, `INVERTIR_MOTOR 1` en el `.ino`.
- El carro **arranca siempre desarmado**. Hay que pulsar ARMAR.
- En el pabellón usa el AP propio de la Pi, no la red del recinto.

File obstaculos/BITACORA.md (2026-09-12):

# Bitácora — sistema de control del Reto de Obstáculos

Traspaso del trabajo sobre `obstaculos/`. El README explica **cómo funciona**
el sistema; esto explica **cómo llegó a ser así**: qué falló, cómo se aisló
cada fallo y por qué la solución es la que es. Si retomas el trabajo —tú,
Cristian, o una sesión nueva— empieza aquí.

Cubre dos tandas: los fallos 1-5 salieron de rodar el carro en pista; los 6-9,
de una segunda sesión desde otro equipo que fue a buscarlos con instrumentos.
Cuatro de esos cuatro estaban en código de la primera tanda.

---

## Estado actual

| | |
|---|---|
| Rama | `obstacle-challenge-control` |
| Base | `main` (`7b9ee69`) |
| Código | ~7.800 líneas: firmware ESP32 + piloto de la Pi 5 |
| Pruebas | **165 comprobaciones**, `python3 tools/selftest.py`, sin hardware |
| Firmware | compila con `arduino-cli`; **no** se ha ejecutado en el ESP32 |
| Verificado en pista | detección y esquive de pilares ✔ |
| Sin verificar en pista | **todo lo demás**: esquinas, líneas del piso, vueltas, parada en meta |

Estados de la FSM (12): `espera · arranque · pista · senal · esquive ·
reincorporacion · esquina · correccion · reversa · meta · fin · fallo`

```
1907f06  La naranja no oscurece el piso, y esa era la puerta
fbe870d  El sensor de color preguntaba siempre un pelo antes de tiempo
d5c4861  La esquina la dice el piso, no la camara
1e55175  Un muro de frente no es un muro al costado
be28742  Sesenta y tres vueltas en treinta centimetros
c6bc1af  Mantener el rumbo no es mantener el volante
8341ffc  Un hueco tiene direccion, no posicion
f3a2c48  Que la altura mande sobre la base, y que el carro no se frene solo
70a604d  Sistema de control para el reto de obstaculos
```

---

## La arquitectura en un párrafo

La Pi 5 piensa, el ESP32 obedece y desconfía. La Pi corre visión, decisión y
una FSM a la velocidad de la cámara (~30 Hz); un hilo aparte reenvía el último
mando a **50 Hz fijos**, de modo que una pausa de visión nunca se confunde con
una Pi muerta. El ESP32 valida CRC, aplica rampas y topes, y corta la tracción
él solo si la Pi calla 300 ms o si su propia tarea de control calla 200 ms. El
motor necesita **dos llaves**: el botón físico (en el ESP32) y `F_ARMADO` (de
la Pi); ninguna basta por sí sola.

---

## Los nueve fallos, y qué enseñó cada uno

### 1. El carro ignoraba el color de los pilares

**Síntoma:** esquivaba a un lado cualquiera, sin mirar rojo ni verde.

**Diagnóstico:** no decidía mal — **no veía ningún pilar**. Había un filtro que
exigía que la distancia deducida de la base y la deducida de la altura
aparente coincidieran. Pero no dependen de lo mismo:

| Medida | Depende de | Con el mástil 4,5° torcido |
|---|---|---|
| por altura | solo `fy_px` | 600 / 900 / 1200 / 1500 mm — exacta |
| por base | `fy` + altura cámara + **inclinación** | 980 / 2100 / 4949 / 6000 mm |

El filtro las comparaba, no se parecían, y descartaba **todos** los pilares en
silencio. Reproducido con fotogramas sintéticos: con la inclinación real a 12°,
detección **0 a todas las distancias**.

**Lección:** el desacuerdo entre dos medidas no era señal de detección falsa,
era señal de calibración imperfecta — o sea, el estado normal el día de la
competencia. Un filtro que descarta ante la duda convierte un error de montaje
de 4° en ceguera total. Ahora la altura manda y la base solo pondera.

> **Regla que sacamos:** ningún filtro debe poder vaciar una detección
> completa sin dejar rastro. De ahí nació `Escena.descartes`, que cuenta qué
> filtro se comió cada contorno y viaja a la telemetría.

### 2. El carro se quedaba «trabado»

Dos causas independientes, las dos reales:

- Un pilar de frente a 1,5 m daba `holgura = 0`, caía bajo el umbral de «lado
  incorrecto» y metía el carro en `CORRECCION` **al 22 %** en cada aproximación
  normal. El lado solo debe juzgarse cuando de verdad se acaba el sitio
  (< 700 mm), no desde lejos.
- `pwmMinArranque` existía en el firmware pero **la trama `CONFIG` no lo
  enviaba nunca**, así que quedaba en 0. A bajo porcentaje el motor zumbaba sin
  moverse. Se extendió `CONFIG` a 7 bytes (compatible con la de 6).

**Lección:** un parámetro que existe en un lado del enlace y no viaja es peor
que no tenerlo, porque se lee el código y parece que está resuelto.

### 3. No seguía la dirección de la pista: chocaba con las paredes

**Dos fallos superpuestos en el mismo cálculo.**

Un sector **libre** no tiene muro, así que no tiene base sobre la que apoyarse.
El código le calculaba igualmente un «lateral en milímetros» usando la fila del
fondo de la imagen, y salía que el hueco estaba a 24 mm del parachoques. El
ángulo resultante era de ~1° y el volante pedía **±7 %** con la curva entera
abierta a un lado.

Y al arreglar eso apareció el segundo: en una recta, media imagen empata en la
distancia máxima, y `np.argmax` devuelve **el primero**, o sea el más a la
izquierda. El carro pedía volante a la izquierda en cada recta aunque fuera
perfectamente centrado.

| Escena | Antes | Después |
|---|---|---|
| curva, salida a la izquierda | −7,4 % | **−73,6 %** |
| curva, salida a la derecha | +6,4 % | **+73,6 %** |
| recta centrada | −50,9 % | **0,0 %** |

**Lección:** un hueco tiene **dirección**, no posición. Pedirle una posición en
el suelo obliga a inventarse una fila, y con la fila equivocada el ángulo sale
nulo. Ahora cada sector lleva su rumbo angular (solo depende de `fx`) y se
apunta al **centro del tramo contiguo libre más ancho**.

De paso se rehízo el centrado, que comparaba distancias *hacia delante* del
tercio izquierdo contra el derecho — eso responde a lo lejos que está el muro,
no a lo pegado que va el carro. Ahora cada sector con muro se convierte en un
punto del suelo y se mide la separación lateral de verdad.

**El sentido de las curvas se aprende.** En una pista WRO todas van hacia el
mismo lado, así que basta acertar una: se promedia el rumbo del hueco durante
la primera curva. El color de la primera línea pisada entra solo como pista de
arranque, y el sentido aprendido siempre manda sobre ella — `color_entrada_horario`
sigue siendo un parámetro adivinado y no puede decidir doce curvas.

### 4. Tras esquivar, seguía girando hacia el pilar

**Síntoma:** pasaba el verde y seguía curvando a la izquierda hasta el muro.

**Diagnóstico:** la fase de compromiso congelaba el **ángulo de volante** del
último fotograma con el pilar a la vista —unos 59 %— durante 0,78 s. Un volante
fijo no traza una recta: traza un arco. Con el modelo Ackermann simplificado,
**537 mm de desvío lateral**, más de medio carril.

El comentario del código ya decía «se mantiene el rumbo». La implementación
mantenía otra cosa.

**Solución:** se congela el **yaw del MPU** del instante en que el pilar entra
en zona ciega, y un proporcional devuelve el carro a ese rumbo. Sin MPU, el
respaldo suelta el volante progresivamente: peor, pero nunca cierra el arco.

Y como durante el compromiso el seguidor de carril está callado a propósito
(si opinara, la rueda trasera barrería el pilar), se añadió `guardia_muro`: no
centra, solo evita el golpe; se calla mientras haya sitio y su autoridad crece
con el progreso del adelantamiento.

**Lección:** mantener el rumbo no es mantener el volante. Cuando un comentario
y su código discrepan, el que está mal suele ser el código — pero hay que
demostrarlo, no suponerlo.

### 5. «Ronda terminada» nada más pulsar el botón

**Síntoma:** `'vueltas': 63, 'cruces': 255, 'dist_m': 0.3`.

255 es la saturación de un contador de 8 bits, y 63 vueltas en 0,3 m es
imposible. Era una **carrera de sincronización**: `preparar()` mandaba
`CAL_CERO_LINEAS`, pero la Pi tomaba su línea base antes de que el ESP32
llegara a aplicarlo. El contador pasaba de 200 a 0 y `(0−200) & 0xFF = 56`
cruces fantasma → 14 vueltas de golpe.

Tres redes, porque una sola no basta:

1. **Salto imposible = resincronizar.** Entre dos ciclos de la Pi no caben más
   de 2-3 cruces reales. Por encima se re-referencia y no se cuenta nada. Un
   envoltorio legítimo (254 → 1) sí sigue contando.
2. **No contar en `ESPERA`.** El carro pasa minutos quieto delante del juez.
3. **Suelo de distancia.** Tres vueltas no caben en tres metros; una vuelta
   real ronda los 8 m.

Y los contadores se ponen a cero **en el flanco del botón**, no al lanzar el
programa: así el cero de los dos lados cae en el mismo instante que el
cronómetro del juez, y la carrera desaparece por construcción.

**Lección:** un contador acumulado de 8 bits es robusto frente a tramas
perdidas —esa era la idea— pero no frente a un **reinicio**. La resta modular
convierte un reset en un salto enorme indistinguible de actividad real. Hay que
decidir explícitamente qué delta es físicamente posible.

### 6. Un muro de frente se contaba como muro al costado

**Síntoma:** el mismo de antes — rebasaba bien y acto seguido se clavaba en la
pared — pero seguía pasando después del arreglo 4.

**Diagnóstico:** la separación lateral metía el muro **frontal** en la cuenta.
Un muro de frente ocupa *todos* los rumbos, y el sector a 4° del morro da
`700 · sen 4° = 49 mm`. Con el carro centrado en un carril de 1000 mm y una
esquina a 700, el código reportaba **muros a 46 mm a los dos lados**. Como la
guardia empuja con la *diferencia*, los dos empujones se cancelaban: daba
exactamente 0 justo cuando hacía falta.

Ahora solo cuenta como costado lo que está más cerca que el frente
(`frac_frente_lateral`). Medido: a 150 mm del muro derecho tras rebasar por la
derecha, el volante pasa de **−12 % a −66 %**.

Dos causas encadenadas más en el mismo commit: el compromiso soltaba el carro
con el rumbo apuntando al lado del rebase (ahora la segunda mitad lo lleva al
rumbo del pasillo libre), y al volver a `PISTA` ese frente cerrado se leía como
esquina — de ahí el estado **`REINCORPORACION`**, que dice explícitamente
«todavía me estoy recolocando».

**Lección:** una magnitud derivada puede ser correcta en su fórmula y aun así
estar midiendo otra cosa. «Distancia lateral» y «distancia a lo que tengo
delante proyectada al lateral» son el mismo número y conceptos distintos.

### 7. Las esquinas eran cosa de la cámara, y la cámara no sabe

**Síntoma:** giraba antes de tiempo y giraba a medias.

**Diagnóstico:** la cámara solo sabe decir «el frente se cerró», y eso le pasa
en una esquina igual que cuando el carro quedó apuntando a un muro tras
rebasar. Además el seguidor de carril renegocia el volante cada ciclo contra el
centrado, así que en cuanto asoma hueco, afloja.

Ahora hay un reparto explícito: **la línea del piso dice CUÁNDO**, la cámara
confirma **QUE ESTÁ AHÍ** (el frente tiene que estar cerrado) y el sentido de la
ronda dice **HACIA DÓNDE**. El estado `ESQUINA` hace un giro comprometido —
`dir_esquina` sostenido hasta `esquina_grados` de yaw, sin renegociar — y entre
esquina y esquina el carro va recto.

Cuatro redes: una esquina = un giro (`dist_entre_esquinas_mm`, porque las dos
líneas caen en los mismos 1000 mm y 90+90 es la pared); `esquina_frente_max_mm`
descarta la línea de *salida* si el TCS se perdió la de entrada; un pilar
interrumpe la curva (8-10 puntos pesan más que trazar bonito); y sin MPU se sale
por tiempo.

**Bonus, encontrado al montar el guion de integración:** `piloto.ciclo` calcula
el carril **antes** que el contador, así que en el ciclo del primer cruce
`sentido_curva` todavía valía 0. Como el evento de esquina dura un solo ciclo,
**la primera curva de la ronda no disparaba nunca**. Un fallo de orden que
ninguna prueba de módulo aislado podía ver.

### 8. El sensor de color preguntaba siempre un pelo antes de tiempo

**Síntoma:** no detectaba bien las líneas. No era el sensor ni los umbrales:
era aritmética.

El chip integra cada `periodoMs` y el firmware preguntaba cada `periodoMs`. Dos
relojes libres a la misma frecuencia **derivan**: la pregunta cae siempre justo
antes de que el dato exista y, como el hueco siguiente ya estaba reservado, el
periodo real **se dobla**. Una línea de 20 mm a 1 m/s dura 20 ms; en un hueco de
48 ms cabe entera sin dejar rastro.

Cuatro arreglos, y los tres últimos salieron al medir el primero: sondear cada
2 ms y coger la muestra cuando `AVALID` lo dice (`atime` 24 → 12 ms);
`leerColor` devolvía `true` aunque siguiera integrando, así que el clasificador
se comía la muestra anterior otra vez; contar la permanencia en milisegundos en
vez de exigir dos lecturas seguidas; y adoptar entera la primera lectura de
blanco, que antes subía desde 1 a razón de 1/64 por muestra y dejaba el carro
**ciego diez segundos al encender**.

**Lección:** muestrear a la misma frecuencia a la que se produce el dato es la
receta del *aliasing*. Hay que sondear más rápido y dejar que el productor diga
cuándo.

### 9. La naranja no oscurece el piso, y esa era la puerta

**Síntoma:** no veía la naranja, y la azul apenas.

**Diagnóstico:** el clasificador exigía que el piso se **oscureciera** por
debajo del 78 % del blanco para admitir que había línea. Pero la naranja es
CMYK(0,60,100,0): refleja rojo y verde casi como el tapete, así que su claro
ronda el umbral y entra o no según la luz de la sala. La azul, oscura, pasaba
siempre. El síntoma era exactamente ese.

**El oscurecimiento nunca fue la prueba de que hay línea.** La prueba es el
color: el tapete da `r−b` casi cero haga la luz que haga. Ahora decide la
magnitud del discriminante con histéresis propia (entra a 45, sale a 25), y del
claro queda solo un suelo del 12 % para descartar el muro negro, donde las
cuentas son ruido.

En el mismo commit, **`activar_desde_mm` no mandaba el alcance: lo mandaba
`area_min`**. Un pilar de 50×100 ocupa del orden de `8,5·10⁸/d²` px — 330 a
1,6 m y 147 a 2,4 m — así que con `area_min = 320` el carro era ciego más allá
de 1,6 m aunque el JSON dijera 2400. Medido con pilares sintéticos: con 320
detecta a 1600 y no a 2000; con 140 llega a 2800.

**Lección:** un parámetro que *parece* gobernar algo puede estar dominado por
otro tres capas más abajo. `activar_desde_mm` era un número decorativo.

> **Herramienta que salió de aquí:** `main.py --lineas`, monitor del sensor de
> color sin cámara ni motor. Se empuja el carro a mano sobre cada línea y dice
> el `|sep|` máximo por color y cuántos cruces contó. Convierte «no las ve» en
> tres diagnósticos con arreglos distintos: el color no llega (ningún umbral
> arregla una señal que no está), el color llega pero el cruce fue demasiado
> rápido, o firmware viejo.

### Y una que no era del código

Un `Device '/dev/video0' is busy` por una ejecución anterior que quedó viva. No
era un fallo nuestro, pero el mensaje `no se pudo abrir la camara` a secas
obligaba a adivinar. Ahora hay `--listar-camaras` (lee `/proc`, no necesita
`fuser` ni `lsof`), `--camara N`, autobúsqueda de índice y un mensaje que
distingue «ocupada por X» de «no hay ningún `/dev/video*`» de «abre pero no da
imagen» (ese último es el nodo de metadatos de la UVC).

---

## Patrón que se repite

Ocho de los nueve tenían la misma forma: **una magnitud calculada con la
fórmula equivocada, que daba un número plausible en vez de un error**. Un pilar
a 4.949 mm, un hueco a 24 mm, un volante congelado al 59 %, un delta de 56
cruces, dos muros a 46 mm a los dos lados, un periodo de muestreo que valía el
doble de lo que decía. Ninguno lanzó una excepción. Ninguno se vio en una
prueba unitaria de la función aislada. Todos se vieron reproduciéndolos con
datos sintéticos y **mirando el número intermedio**.

Dos variantes que conviene reconocer aparte, porque no se cazan mirando una
función:

- **El parámetro decorativo.** `activar_desde_mm` decía 2400 y el alcance real
  lo fijaba `area_min` tres capas más abajo. `pwmMinArranque` existía en el
  firmware y la trama nunca lo enviaba. El código se lee y parece resuelto.
- **El fallo de orden.** El carril se calculaba antes que el contador, así que
  en el ciclo del primer cruce el sentido aún valía 0 y la primera curva no
  disparaba nunca. Cada módulo estaba bien; el guion estaba mal.

Por eso el `selftest.py` de este proyecto no prueba «que la función devuelva
algo»: prueba **que el carro gire hacia el lado correcto** en escenas
fabricadas, incluida la cámara mal calibrada a 10°, 12° y 14°.

---

## Calibración, en orden. Saltárselo es perder una tarde

1. **Servo** — `centro` deja las ruedas rectas; `izquierda`/`derecha` sin topar
   la cremallera. Los topes duros están en `seguridad.h` como constantes de
   compilación: el JSON solo puede estrechar.
2. **`fy_px`** — es el que de verdad importa. La distancia a un pilar sale de
   su altura aparente. `inclinacion_deg` y `alto_cam_mm` son secundarios **a
   propósito** desde el fallo 1.
3. **Colores HSV** — con `--ver`, sobre el tapete y la luz reales. Lo que
   importa no es que el pilar se vea entero: es que **nada más** se vea.
4. **`pwm_min_motor`** — de 5 en 5 desde 55, hasta que arranque limpio desde
   parado y ni uno más.
5. **`mm_s_por_pct`** — 40 % durante 3 s en recta, medir, dividir.
6. **`color_entrada_horario`** — empujar el carro a mano en sentido horario y
   mirar qué color reporta el primer cruce. **Sigue sin verificarse.**

---

## Lo que queda pendiente

- **⚠ EL RANGO DEL SERVO ESTÁ SIN COMPROBAR CONTRA LA MECÁNICA.** Pasó de
  65/135 a **58/142** para poder cerrar más las curvas. Los topes duros de
  `seguridad.h` son 50/145, así que el software lo admite — pero eso no dice
  nada de la cremallera. **Antes de rodar: carro levantado, mandar tope a tope
  y comprobar que no hace tope mecánico.** Si lo hace, el servo se queda
  empujando contra el final de carrera y se rompe. Es lo único pendiente que
  puede romper hardware.
- **Los umbrales de color son una estimación, no una medida.** Entra a 45, sale
  a 25. Usar `main.py --lineas` sobre el tapete real **antes** de tocarlos.
- **El firmware compila (`arduino-cli`) pero no se ha ejecutado.** Necesita
  **core ESP32 3.x** (usa `ledcAttach`) y la carpeta debe llamarse igual que el
  `.ino`. Y hay que **reflashear**: la trama de sensores creció a 16 bytes.
  La Pi tolera firmware viejo a propósito (lee los 4 bytes extra solo si están),
  pero entonces no hay diagnóstico de líneas.
- **Todo lo que no sea detectar y esquivar pilares está sin probar en pista.**
  Esquinas, líneas del piso, vueltas y parada en meta solo tienen evidencia
  sintética. Es lo siguiente que hay que rodar.
- **`color_entrada_horario` sin verificar.** Mitigado dos veces (el sentido de
  las curvas se aprende, y ahora lo confirma el par ordenado de la esquina),
  pero conviene fijarlo.
- **`margen_verde_mm` (100) ≠ `margen_rojo_mm` (70) es una compensación, no un
  arreglo.** El punto de paso es simétrico en el código; si en pista pasa más
  cerca del verde, lo más probable es que la máscara del verde recorte el pilar
  y la distancia salga mayor. Merece medirse en vez de compensarse.
- **Un pilar cada vez.** Con dos seguidos se resuelve el primero y el segundo
  se replantea después.
- **Sin encoder.** El odómetro se integra del porcentaje de mando (10-15 % de
  error). Por eso el detector de atasco mira la imagen y no la velocidad
  estimada: preguntarle al acelerador si el coche se mueve no sirve cuando
  está clavado contra un muro.
- **Nada de estacionamiento**, por decisión de alcance. Los delimitadores
  magenta sí se detectan, pero como muro intocable: tocarlos termina la ronda
  (9.25.7).

---

## Qué mirar cuando algo falle

| Síntoma | Primera línea de la telemetría a mirar |
|---|---|
| ignora los pilares | `pilares vistos` y `descartes` |
| no gira en las curvas | `hueco a N deg` y `curvas hacia ...` |
| se va contra el muro tras esquivar | `comp_err_rumbo` y `guardia` |
| termina la ronda antes de tiempo | `vueltas` contra `dist_m`, y `resync` |
| no ve las líneas del piso | `python3 main.py --lineas`, empujando a mano |
| gira antes de tiempo o a medias | si entra en `ESQUINA` por línea o por cámara |
| hace una ese al salir del rebase | `REINCORPORACION`: sale por enfilado, no por centrado |
| no abre la cámara | `python3 main.py --listar-camaras` |

El README tiene una tabla de triaje por cada uno de estos casos.

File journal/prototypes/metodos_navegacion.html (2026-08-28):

WRO 2026 · Futuros Ingenieros · carro autónomo

# Cinco trazados

Cinco maneras de decidir por dónde pasa el carro, ordenadas por lo que aportan sobre lo que ya funciona. Las tres primeras, a fondo.

Base: perfil de contacto muro–piso, columna por columna Encima: centrado · pared · esquina interna · rumbo

| Método | Qué añade | Coste en la Pi 5 | Estado
01 | Hueco pasable | Comprueba que el carro cabe, no solo que se ve hueco | +0.4 ms/frame | implementado
02 | Arcos de dirección | Tiene en cuenta el radio de giro y la inercia | +2–4 ms/frame | siguiente paso
03 | Mezcla por confianza | Cada navegación pesa según lo fiable que sea ahora mismo | +0.1 ms/frame | siguiente paso
04 | Vista de pájaro | Geometría real en centímetros, no en píxeles | +3 ms/frame | no antes de la competencia
05 | Histograma polar (VFH+) | Sectores angulares con histéresis | +1 ms/frame | redundante con 01

01

## Hueco pasable, medido con el ancho de las ruedas

Un hueco que se ve no es un hueco por el que se pasa. La diferencia son dos números: cuántos píxeles mide el hueco y cuántos mide el carro a esa distancia.

### Cómo funciona

Del perfil de contacto salen tramos consecutivos con espacio libre por encima de un umbral. Cada tramo es un candidato. Para cada uno se mira el obstáculo más cercano de los dos que lo delimitan y, con la fila donde ese obstáculo toca el suelo, se calcula cuántos píxeles de ancho ocuparía el carro justo ahí.

La conversión no necesita patrón de calibración ni conocer la focal: en un plano de suelo, un ancho real fijo se ve proporcional a (y − horizonte). Y ya tienes anclado el extremo cercano, porque las dos líneas verticales de las ruedas están calibradas a mano en la fila de abajo. Con eso basta para escalar.

El mismo hueco de 66 píxeles es holgado cuando los obstáculos están lejos y es un choque cuando están cerca. Comparar anchos en píxeles sin corregir la perspectiva es lo que hace que un esquive parezca correcto en pantalla y raspe en la pista.

### Por qué encaja en este carro

Es el único de los cinco que responde a la pregunta del reto de obstáculos tal cual está planteada: dejar el pilar rojo a un lado y el verde al otro pasando entre ellos y el muro. Un hueco es exactamente eso, y la puntuación ya incluye el siguiente obstáculo: si detrás de la boca hay otra cosa, la parte profunda del tramo tiene poco espacio libre y el candidato pierde puntos aunque la entrada sea ancha.

### Dónde falla

- Apunta a un punto, no a una trayectoria. Si el hueco exige más giro del que da el servo, lo elige igual. Eso lo arregla el método 02.
- El horizonte es un parámetro, no una medida. Si mueves la cámara de sitio hay que volver a ajustarlo (está en el panel).
- Con el muro muy cerca todo el perfil baja del umbral y no queda ningún hueco: ahí manda la capa de escape, no esta.

Veredicto

Implementado y mezclable con las otras dos. Es la base del reto de obstáculos y no hay razón para no llevarlo activo con peso bajo incluso en la pista vacía: cuesta 0.4 ms y da un candidato de respaldo cuando el centrado duda.

02

## Arcos de dirección: elegir la curva, no el punto

El carro no se mueve hacia donde apunta. Se mueve por un arco que depende del ángulo del servo. Evaluar arcos en vez de puntos es lo que resuelve la inercia de raíz.

### Cómo funciona

En cada frame se prueban entre 9 y 15 ángulos de dirección repartidos por todo el recorrido del servo. Para cada uno se dibuja el arco que el carro recorrería en el próximo segundo — con dirección Ackermann, radio ≈ batalla / tan(ángulo) — y se comprueba si ese arco, ensanchado el ancho del carro, choca con el perfil del muro.

Cada arco recibe una puntuación con tres términos: cuánto se avanza antes de tocar algo, cuánto se aleja del muro más cercano y cuánto se parece al ángulo actual (para no dar bandazos). Gana el mejor, y el rango de ángulos considerados se recorta por la velocidad actual: yendo rápido, los giros cerrados ni se evalúan.

Apuntar al centro del hueco supone que el carro puede ir en línea recta hacia allí. Con dirección Ackermann y algo de velocidad, la trayectoria real es un arco que empieza casi recto: llega al hueco desplazado y raspa la esquina interior. Evaluar el arco detecta ese roce un segundo antes de que ocurra.

### Por qué encaja en este carro

El problema que describiste — «pasa de crucero a girar, va con inercia, se acerca demasiado al muro» — tiene dos capas. La anticipación por tiempo hasta el muro, ya implementada, ataca la velocidad. Esto ataca la geometría: si el arco necesario no existe a la velocidad actual, la puntuación de todos los arcos cae a la vez, y esa caída es una señal de frenado mucho más honesta que un umbral de distancia.

También hace innecesario el ajuste fino de dir_giro_abierto. Hoy el giro abierto es una constante que pusiste a ojo para que las ruedas traseras no barran la esquina interna; con arcos, el ángulo abierto sale solo porque el arco cerrado se descarta por colisión.

### Dónde falla

- Necesita saber la batalla del carro (distancia entre ejes) y el ángulo real de las ruedas, no el del servo. Son dos medidas con un metro, pero hay que hacerlas.
- Es el más caro de los cinco: 15 arcos × 40 puntos de muestreo. En la Pi 5 son 2–4 ms con numpy vectorizado; a 30 FPS sobra, pero ya no es gratis.
- Un perfil de muro mal calibrado se traduce en arcos descartados sin motivo y el carro se queda quieto sin razón aparente. Hay que ver los arcos dibujados para depurarlo — y eso es trabajo de interfaz, no solo de algoritmo.

Veredicto

El que más mejora daría, y el que más trabajo cuesta. Si queda una tarde antes de la competencia, esta es la tarde. Encaja como una cuarta entrada en la mezcla, sin tocar nada de lo demás.

03

## Mezcla por confianza: que cada navegación pese lo que vale ahora

Los pesos fijos obligan a elegir de antemano. Pero cada estrategia sabe cuándo está ciega, y esa información hoy se tira.

### Cómo funciona

Cada estrategia devuelve, además de su dirección, un número de 0 a 1 que dice cuánto se fía de sí misma en este frame:

- Centrado: alta cuando las dos bandas laterales ven muro; baja en cuanto una de las dos se queda sin nada que medir — que es justo lo que pasa al llegar a la esquina interna.
- Pared: alta mientras la banda seguida tenga muro continuo; se desploma en el hueco de la esquina, que es donde hoy gira tarde.
- Hueco: alta cuando el mejor candidato tiene margen de sobra y hay un solo hueco claro; baja cuando hay tres empatados o ninguno cabe.

El peso final es el que fijaste en la interfaz multiplicado por esa confianza, y se renormaliza. Los sliders siguen mandando; lo que cambia es que una estrategia ciega deja de arrastrar la decisión.

La estrategia de pared sigue votando en la esquina, pero con confianza 0.1 su voto casi no pesa. Es la misma mezcla que ya tienes, con un multiplicador que las propias estrategias calculan.

### Por qué encaja en este carro

Es el cambio más barato de los tres: unas cuarenta líneas, ningún parámetro nuevo que calibrar en pista y ningún riesgo de romper lo que ya funciona, porque con todas las confianzas a 1 el comportamiento es exactamente el de hoy. Y ataca directamente lo que observaste del seguimiento de pared: no gira tarde por estar mal ajustado, gira tarde porque en la esquina no tiene pared que seguir y sigue opinando igual de fuerte.

### Dónde falla

- Una confianza mal calculada es peor que no tenerla: si el centrado se cree fiable cuando no lo es, ahora además silencia a los otros dos.
- Hay que poder verla. Sin las tres confianzas en pantalla junto a los aportes, depurar un comportamiento raro pasa de difícil a imposible.

Veredicto

Lo primero que haría, antes que el 02. Barato, reversible, y convierte los tres sliders de la interfaz en algo que se puede dejar puesto en vez de tener que elegir estrategia según el tramo.

04 · 05

## Los dos que no haría ahora

04 · Vista de pájaro

Rectificar el piso con una homografía y trabajar en centímetros sobre una vista cenital. Es lo correcto: el ancho del carro deja de depender de la fila de la imagen y el trazado se puede planificar con geometría de verdad. El precio es una calibración con patrón de tablero, una cámara que no se mueva ni un milímetro y un frame más que procesar. A una semana de competir, es cambiar algo que funciona por algo que hay que volver a calibrar.

05 · Histograma polar (VFH+)

Convertir el perfil en sectores angulares, marcar los bloqueados ensanchándolos el radio del carro y elegir el valle libre más cercano al rumbo, con histéresis para no oscilar entre dos valles parecidos. Es sólido y clásico, pero hace casi lo mismo que el método 01 con otra aritmética. Lo único que aporta de verdad es la histéresis — y esa se puede añadir al hueco en cinco líneas sin traer el resto.

→

## En qué orden

Primero, medir. Con lo que ya hay puesto: da vueltas con el centrado y mira en carrito.local el ancho de carril autocalibrado, los segundos hasta el muro en las esquinas y cuántas veces entra en escape. Esos tres números dicen si hace falta el 02 o si con ajustar ttc_min basta.

Después, la mezcla por confianza (03). Una tarde, reversible, y arregla el «gira tarde» de la pared sin tocar sus ganancias.

Solo si sobra tiempo, los arcos (02). Mide antes la batalla y el ángulo real de las ruedas: sin esos dos números el método no vale nada, y con ellos vale más que los otros cuatro juntos.

La histéresis del 05 se puede robar en cualquier momento: no cambiar de hueco elegido mientras el actual siga siendo pasable y su puntuación esté a menos de un 15 % del mejor. Cinco líneas dentro de detectar_huecos.

Los tres métodos analizados se conectan como una entrada más en la mezcla de navegacion.py. Ninguno sustituye a la capa de seguridad: el frenado por espacio libre y el escape hacia adelante corren por debajo de cualquier estrategia.

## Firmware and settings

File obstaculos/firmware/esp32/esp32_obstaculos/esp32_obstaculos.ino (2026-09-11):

// ===========================================================================
// esp32_obstaculos.ino — Controlador de hardware del carro WRO Future
// Engineers, RETO DE OBSTACULOS.
//
// El ESP32 no tiene WiFi, ni pagina web, ni decisiones. Es un controlador de
// hardware puro que obedece tramas binarias por serial. Toda la inteligencia
// (camara, planificacion, maquina de estados) vive en la Raspberry Pi 5.
// Razones, en orden de importancia:
//
//   1. UNA sola fuente de ordenes: no hay que arbitrar quien manda.
//   2. Si la Pi se cuelga, el ESP32 para el carro EL SOLO. Esa es justamente
//      la razon de tener un microcontrolador en medio y no un puente H
//      colgado del GPIO de la Pi.
//   3. Los ~40 KB de RAM y el nucleo 0 quedan libres para atender el serial
//      sin jitter, que es lo que hace que el lazo de control sea de verdad
//      de 100 Hz y no "100 Hz cuando Linux quiere".
//
// ENLACE: escucha las DOS bocas a la vez y contesta por la que recibio la
// ultima trama valida. El mismo binario sirve por USB (banco de pruebas) y
// por GPIO (carrera), sin recompilar.
//     Serial   -> USB / UART0
//     Serial2  -> GPIO16 = RX2, GPIO17 = TX2, cruzados contra la Pi
//
// REPARTO DE TAREAS FreeRTOS
//   nucleo 0: tareaRx (prio 5)         lee UARTs, valida CRC, publica mando
//             tareaSensores (prio 3)   MPU-6050 + TCS34725, despertada por
//                                      las patas INT (latido de 5 ms)
//             tareaTelemetria (prio 2) estado a 20 Hz, sensores a 40 Hz
//   nucleo 1: tareaControl (prio 4)    tick de 10 ms: boton, rampas, HW
//             tareaVigilante (prio 6)  si el control o la Pi se callan, corta
//
// Nucleo 1 solo tiene control y vigilante a proposito: nada que pueda
// bloquear (I2C, serial) comparte nucleo con lo que mueve el motor.
//
// REQUISITO: Arduino-ESP32 core 3.x (API ledcAttach / ledcWrite por pin).
// ===========================================================================

#include <Arduino.h>
#include <Wire.h>

#include "protocolo.h"
#include "seguridad.h"
#include "sensores_i2c.h"
#include "lineas.h"
#include "panel.h"

// ============================== PINES =====================================
// Traccion: driver IBT-2 (BTS7960), motor DC de 500 rpm.
const int PIN_RPWM = 25;    // PWM adelante
const int PIN_LPWM = 26;    // PWM atras
const int PIN_R_EN = 27;    // habilitacion de la media puente derecha
const int PIN_L_EN = 33;    // habilitacion de la media puente izquierda

// Direccion: servo MG996R sobre cremallera Ackermann.
const int PIN_SERVO = 32;

// I2C compartido: MPU-6050 (0x68) + TCS34725 (0x29).
const int PIN_SDA = 21;
const int PIN_SCL = 22;
const uint32_t I2C_HZ = 400000;

// Patas INT de los sensores. Las dos son OPCIONALES: si no estan cableadas el
// firmware lo detecta solo y sigue por sondeo (mas lento y con mas jitter).
const int PIN_INT_MPU = 18;   // push-pull, activo ALTO   (data ready)
const int PIN_INT_TCS = 19;   // open-drain, activo BAJO  (borde de linea)

// UART hacia la Raspberry Pi.
const int PIN_RX2 = 16;       // <- TX de la Pi
const int PIN_TX2 = 17;       // -> RX de la Pi
const uint32_t BAUDIOS = 115200;   // 8N1

// Pulsador de competencia, entre el pin y GND (pull-up interno). El 13 no es
// pin de arranque ni de entrada-sola: pisado al encender no impide el boot.
const int PIN_BOTON = 13;
// LED de estado: el azul de a bordo (GPIO 2 en casi todas las placas).
const int PIN_LED = 2;

// Si el carro avanza al reves, cambia esto a 1 en vez de recablear el motor.
#define INVERTIR_MOTOR 0

// ============================== PWM =======================================
const int MOTOR_PWM_FREQ = 20000;   // 20 kHz: fuera del rango audible y lejos
const int MOTOR_PWM_RES  = 8;       //   de la banda donde el IBT-2 silba
const int SERVO_PWM_FREQ = 50;      // 50 Hz estandar de servo
const int SERVO_PWM_RES  = 16;      // 16 bits: ~0.3 us de resolucion de pulso
const int SERVO_PULSO_MIN_US = 500;
const int SERVO_PULSO_MAX_US = 2400;

// ============================== TIEMPOS ===================================
const uint32_t TICK_CONTROL_MS  = 10;    // 100 Hz
const uint32_t PERIODO_TELE_MS  = 50;    // 20 Hz
const uint32_t PERIODO_SENS_MS  = 25;    // 40 Hz
const uint32_t FAILSAFE_MS      = 300;   // silencio tolerado de la Pi
const uint32_t VIGILANTE_MS     = 200;   // silencio tolerado del propio control
const uint32_t REINTENTO_I2C_MS = 3000;  // resondeo de sensores que falten

const uint8_t VERSION_FIRMWARE = 1;

// ====================== ESTADO COMPARTIDO =================================
QueueHandle_t colaMando = NULL;          // longitud 1: el nuevo pisa al viejo

volatile uint32_t msUltimoMando   = 0;
volatile uint32_t msUltimoControl = 0;
volatile uint8_t  ultimaSeq       = 0;
volatile uint8_t  estadoBits      = 0;
volatile uint8_t  pwmActual       = 0;
volatile uint8_t  anguloActual    = 100;
volatile uint32_t tramasMalas     = 0;
volatile int8_t   enlaceActivo    = -1;  // 0 = USB, 1 = GPIO, -1 = ninguno

// ARMADO LOCAL: lo pone y lo quita el BOTON, aqui, sin preguntar a la Pi.
// El motor solo gira si ademas la Pi manda F_ARMADO. Dos llaves, una a cada
// lado del enlace: ninguna sola basta.
volatile bool armadoLocal = false;
volatile bool cortadoPorBoton = false;

seg::ControlServo servo;
seg::ControlMotor motor;

panel::Boton boton;
panel::Led   led;
volatile uint8_t bitsBoton = 0;
volatile uint8_t pulsacionesPub = 0;

// --- sensores I2C: los toca solo tareaSensores; la copia publicada se
//     protege con spinlock porque telemetria la lee desde el otro nucleo ---
sens::Mpu6050 mpu;
sens::Tcs34725 tcs;
lin::Clasificador lineas;
proto::Sensores sensoresPub = {0, 0, 0, 0, 0, 0, 0, 0, VERSION_FIRMWARE};
portMUX_TYPE muxSensores = portMUX_INITIALIZER_UNLOCKED;

volatile uint8_t calPendiente = 0;       // proto::CAL_* pedido por la Pi
volatile bool    cfgPendiente = false;
seg::ConfigServo cfgServoNueva;
seg::ConfigMotor cfgMotorNueva;

// Umbral de la INT del TCS, en % del blanco que el firmware aprende solo.
// Al ser relativo no se estropea si cambia el tiempo de integracion.
// Umbral de la INT del TCS, en % del blanco aprendido. Con 55 no saltaba
// nunca para la naranja, que apenas oscurece el piso. Desde que se sondea a
// 500 Hz la INT solo es un adelanto —no se depende de ella para nada— pero
// un umbral que ignora medio juego de lineas es mentira en el codigo.
const uint8_t PCT_UMBRAL_INT = 90;

// ----------------------- interrupciones de sensores ------------------------
// Los ISR NO tocan el I2C (Wire no es seguro dentro de una interrupcion):
// solo apuntan CUANDO paso y despiertan a tareaSensores, que es la que lee.
TaskHandle_t hSensores = NULL;
static const uint32_t AVISO_MPU = (1u << 0);
static const uint32_t AVISO_TCS = (1u << 1);
volatile uint32_t usIntMpu = 0, usIntTcs = 0;
volatile uint32_t nIntMpu = 0, nIntTcs = 0;

void IRAM_ATTR isrMpu() {
  usIntMpu = micros();
  nIntMpu++;
  BaseType_t despertar = pdFALSE;
  if (hSensores) xTaskNotifyFromISR(hSensores, AVISO_MPU, eSetBits, &despertar);
  if (despertar) portYIELD_FROM_ISR();
}

void IRAM_ATTR isrTcs() {
  usIntTcs = micros();
  nIntTcs++;
  BaseType_t despertar = pdFALSE;
  if (hSensores) xTaskNotifyFromISR(hSensores, AVISO_TCS, eSetBits, &despertar);
  if (despertar) portYIELD_FROM_ISR();
}

HardwareSerial *enlaces[2] = { &Serial, &Serial2 };
proto::Lector lectores[2];

// ============================ HARDWARE ====================================
static inline void escribirServoHW(int angulo) {
  // Cuarta red: aunque llegue aqui un valor imposible, no sale del rango.
  angulo = seg::lim(angulo, seg::SERVO_TOPE_MIN, seg::SERVO_TOPE_MAX);
  int pulsoUs = map(angulo, 0, 180, SERVO_PULSO_MIN_US, SERVO_PULSO_MAX_US);
  uint32_t duty = (uint32_t)((pulsoUs / 20000.0) * 65535.0);
  ledcWrite(PIN_SERVO, duty);
  anguloActual = (uint8_t)angulo;
}

static inline void escribirMotorHW(int pwmFirmado) {
#if INVERTIR_MOTOR
  pwmFirmado = -pwmFirmado;
#endif
  if (pwmFirmado > 0) {
    ledcWrite(PIN_LPWM, 0);
    ledcWrite(PIN_RPWM, pwmFirmado);
  } else if (pwmFirmado < 0) {
    ledcWrite(PIN_RPWM, 0);
    ledcWrite(PIN_LPWM, -pwmFirmado);
  } else {
    ledcWrite(PIN_RPWM, 0);
    ledcWrite(PIN_LPWM, 0);
  }
  pwmActual = (uint8_t)abs(pwmFirmado);
}

// Habilitacion del puente H. Bajar R_EN/L_EN deja el IBT-2 en alta impedancia:
// es una parada MAS FUERTE que poner el PWM a cero, porque no depende de que
// el registro de PWM tenga el valor que creemos.
static inline void habilitarPuente(bool on) {
  digitalWrite(PIN_R_EN, on ? HIGH : LOW);
  digitalWrite(PIN_L_EN, on ? HIGH : LOW);
}

// ============================ ENVIOS ======================================
static void enviarPorEnlaceActivo(const uint8_t *trama, uint8_t n) {
  if (n == 0) return;
  int8_t e = enlaceActivo;
  if (e < 0) {                       // aun no hablo nadie: contesta por las dos
    Serial.write(trama, n);
    Serial2.write(trama, n);
    return;
  }
  enlaces[e]->write(trama, n);
}

static void enviarLog(const char *texto) {
  uint8_t trama[5 + proto::MAX_PAYLOAD];
  uint8_t n = (uint8_t)strnlen(texto, proto::MAX_PAYLOAD);
  uint8_t total = proto::empaquetar(proto::TIPO_LOG, (const uint8_t *)texto, n,
                                    trama);
  enviarPorEnlaceActivo(trama, total);
}

// ============================ TAREA RX ====================================
// Prioridad alta (5) y nucleo 0. Solo hace tres cosas: sacar bytes de las dos
// UARTs, validar CRC y publicar. No calcula nada: cualquier trabajo aqui se
// paga en latencia de mando, que es lo unico que el failsafe puede confundir
// con "la Pi murio".
void tareaRx(void *) {
  uint8_t payload[proto::MAX_PAYLOAD];
  uint8_t tipo = 0, n = 0;
  uint32_t malas = tramasMalas;

  for (;;) {
    bool hubo = false;
    for (int e = 0; e < 2; e++) {
      while (enlaces[e]->available()) {
        hubo = true;
        uint8_t b = (uint8_t)enlaces[e]->read();
        if (!lectores[e].alimentar(b, tipo, payload, n, malas)) continue;

        enlaceActivo = (int8_t)e;      // contesta por donde te hablaron
        tramasMalas = malas > 255 ? 255 : malas;

        switch (tipo) {
          case proto::TIPO_MANDO: {
            proto::Mando m;
            if (!proto::decodificarMando(payload, n, m)) break;
            msUltimoMando = millis();
            ultimaSeq = m.seq;
            xQueueOverwrite(colaMando, &m);   // el nuevo pisa al viejo
            break;
          }
          case proto::TIPO_PING: {
            uint8_t trama[8];
            uint8_t eco = n ? payload[0] : 0;
            uint8_t t = proto::empaquetar(proto::TIPO_PONG, &eco, 1, trama);
            enviarPorEnlaceActivo(trama, t);
            break;
          }
          case proto::TIPO_CONFIG: {
            if (n < 6) break;
            cfgServoNueva.centro       = payload[0];
            cfgServoNueva.izquierda    = payload[1];
            cfgServoNueva.derecha      = payload[2];
            cfgServoNueva.gradosPorSeg = payload[3] * 10;
            cfgMotorNueva.rampaPorTick = payload[4];
            cfgMotorNueva.msFrenoAntesDeInvertir = payload[5] * 10;
            // PWM MINIMO DE ARRANQUE (byte 7, opcional).
            // Un PWM de 40 no mueve un motor de 500 rpm cargado con el peso
            // del carro y la reduccion del diferencial: solo calienta el
            // driver y hace zumbar el motor, y desde fuera parece que el
            // carro "se traba". Por debajo de este valor se empuja al minimo
            // util. Se lee condicionalmente para seguir aceptando la trama
            // vieja de 6 bytes sin romper nada.
            if (n >= 7) cfgMotorNueva.pwmMinArranque = payload[6];
            cfgPendiente = true;
            break;
          }
          case proto::TIPO_CAL:
            if (n >= 1) calPendiente = payload[0];
            break;
          default:
            break;
        }
      }
    }
    // Sin bytes: cede el nucleo 1 ms. Con bytes: vuelve enseguida, porque un
    // burst de la Pi cabe entero en el FIFO y no queremos dejarlo enfriar.
    vTaskDelay(hubo ? 0 : pdMS_TO_TICKS(1));
  }
}

// ========================= TAREA SENSORES =================================
// Nucleo 0, prioridad 3. Duerme hasta que una INT la despierta, con un latido
// de 5 ms como red por si las patas INT no estan cableadas.
void tareaSensores(void *) {
  vTaskDelay(pdMS_TO_TICKS(300));      // el riel de 5 V tiene que asentarse

  mpu.detectar();
  tcs.detectar();

  // Calibracion automatica del giroscopio al arrancar. El reglamento (9.9)
  // prohibe "realizar calibraciones de sensores en el vehiculo" como forma de
  // meter datos: por eso esto NO lo dispara nadie, se hace solo al encender,
  // con el carro donde el juez lo dejo, y el LED avisa para que nadie lo mueva.
  if (mpu.presente) mpu.calibrar(400);

  if (tcs.presente) tcs.probarInterrupcion(PIN_INT_TCS);
  if (mpu.presente) {
    uint32_t antes = nIntMpu;
    vTaskDelay(pdMS_TO_TICKS(50));
    mpu.int_ok = (nIntMpu - antes) > 5;    // a 200 Hz deberian ser ~10
  }
  if (tcs.presente && tcs.int_ok)
    tcs.configurarInterrupcion(lineas.umbralInterrupcion(PCT_UMBRAL_INT));

  uint32_t usPrevMpu = micros();
  uint32_t msPrevTcs = millis();
  uint32_t msProxSondeo = millis() + REINTENTO_I2C_MS;

  for (;;) {
    uint32_t aviso = 0;
    // 2 ms, no 5. El sondeo del TCS sale de esta espera, y cada milisegundo
    // que se tarda en preguntar se suma al periodo real de muestreo: con 12 ms
    // de integracion y 5 de granularidad salen ~17 ms entre muestras, y en una
    // linea de 20 mm eso deja UNA sola lectura. Con 2 quedan ~14 y caben dos.
    xTaskNotifyWait(0, 0xFFFFFFFF, &aviso, pdMS_TO_TICKS(2));
    uint32_t ahora = millis();

    // ---- comandos de calibracion pedidos por la Pi ---------------------
    uint8_t cal = calPendiente;
    if (cal) {
      calPendiente = 0;
      if (cal == proto::CAL_SESGO_GIRO)      mpu.calibrar(400);
      else if (cal == proto::CAL_CERO_YAW)   mpu.ceroYaw();
      else if (cal == proto::CAL_CERO_LINEAS) lineas.reiniciar();
      else if (cal == proto::CAL_REDETECTAR) {
        mpu.detectar();
        tcs.detectar();
        if (tcs.presente) tcs.probarInterrupcion(PIN_INT_TCS);
      }
    }

    // ---- MPU: integrar el rumbo con el dt real -------------------------
    if (mpu.presente) {
      uint32_t usAhora = mpu.int_ok ? usIntMpu : micros();
      uint32_t dt = usAhora - usPrevMpu;
      if (dt > 0) { mpu.paso_us(dt); usPrevMpu = usAhora; }
    }

    // ---- TCS: PREGUNTAR MUCHO, COGER LA MUESTRA EN CUANTO EXISTA -------
    //
    // Aqui habia un fallo que dejaba al carro ciego a las lineas la mitad de
    // las veces, y no se ve mirando el sensor: se ve haciendo la cuenta. El
    // chip integra durante `periodoMs()` y el codigo preguntaba CADA
    // `periodoMs()`. Dos relojes a la misma frecuencia, sin sincronizar,
    // derivan; y en cuanto derivan la pregunta cae siempre un pelo ANTES de
    // que el dato exista. Como el hueco hasta la pregunta siguiente ya estaba
    // reservado, el periodo real pasaba a ser el DOBLE. Una linea de 20 mm a
    // 1 m/s dura 20 ms: en un hueco de 48 ms cabe entera sin dejar rastro.
    //
    // La solucion no es afinar el periodo —dos relojes libres siempre acaban
    // derivando— sino dejar de programarlo: se sondea en cada vuelta de la
    // tarea (~200 Hz) y se coge la muestra en el instante en que el chip dice
    // que vale. Asi el periodo real ES el de integracion, sin depender de que
    // dos relojes se lleven bien. Preguntar de mas cuesta una lectura de un
    // byte por I2C: nada al lado de perderse una linea.
    if (tcs.presente) {
      if (tcs.leerColor()) {
        uint16_t dt = (uint16_t)(ahora - msPrevTcs);
        msPrevTcs = ahora;
        lineas.paso(tcs.c, tcs.r, tcs.g, tcs.b, dt ? dt : 1);
        // El umbral de la INT sigue al blanco aprendido: se reajusta solo,
        // despacio, para que no haya que recalibrar al cambiar de sala.
        if (tcs.int_ok) {
          uint16_t u = lineas.umbralInterrupcion(PCT_UMBRAL_INT);
          if (u > tcs.umbral_int + 30 || u + 30 < tcs.umbral_int)
            tcs.configurarInterrupcion(u);
          else
            tcs.limpiarInterrupcion();
        }
      }
    }

    // ---- resondeo de lo que falte --------------------------------------
    if ((int32_t)(ahora - msProxSondeo) >= 0) {
      msProxSondeo = ahora + REINTENTO_I2C_MS;
      if (!mpu.presente) mpu.detectar();
      if (!tcs.presente) tcs.detectar();
    }

    // ---- publicar copia coherente para la telemetria --------------------
    proto::Sensores s;
    s.estado = 0;
    if (mpu.presente)      s.estado |= proto::S_MPU_OK;
    if (tcs.presente)      s.estado |= proto::S_TCS_OK;
    if (mpu.calibrando)    s.estado |= proto::S_CALIBRANDO;
    if (lineas.sobreLinea()) s.estado |= proto::S_SOBRE_LINEA;
    if (mpu.int_ok)        s.estado |= proto::S_MPU_INT;
    if (tcs.int_ok)        s.estado |= proto::S_TCS_INT;
    s.estado |= (uint8_t)(lineas.clase << 6);
    s.yaw_d10 = (int16_t)(mpu.yaw * 10.0f);
    s.gz_d10  = (int16_t)(mpu.gz * 10.0f);
    s.claro   = tcs.c;
    s.blanco = lineas.blanco;
    s.separacion = lineas.separacion;
    s.cruces_naranja = lineas.cruces_naranja;
    s.cruces_azul    = lineas.cruces_azul;
    s.botones     = bitsBoton;
    s.pulsaciones = pulsacionesPub;
    s.version     = VERSION_FIRMWARE;

    portENTER_CRITICAL(&muxSensores);
    sensoresPub = s;
    portEXIT_CRITICAL(&muxSensores);
  }
}

// ======================== TAREA TELEMETRIA ================================
// Nucleo 0, prioridad 2 (la mas baja): si algo tiene que perder un turno, que
// sea contar lo que pasa, no hacerlo.
void tareaTelemetria(void *) {
  uint32_t proxTele = 0, proxSens = 0;
  uint8_t trama[5 + proto::MAX_PAYLOAD];

  for (;;) {
    uint32_t ahora = millis();

    if ((int32_t)(ahora - proxTele) >= 0) {
      proxTele = ahora + PERIODO_TELE_MS;
      proto::Telemetria t;
      t.seq_eco = ultimaSeq;
      t.estado  = estadoBits;
      t.pwm     = pwmActual;
      t.angulo  = anguloActual;
      uint32_t d = ahora - msUltimoMando;
      t.ms_desde_mando = (uint16_t)(d > 65535 ? 65535 : d);
      t.tramas_malas = (uint8_t)tramasMalas;
      t.version = VERSION_FIRMWARE;
      enviarPorEnlaceActivo(trama, proto::empaquetarTelemetria(t, trama));
    }

    if ((int32_t)(ahora - proxSens) >= 0) {
      proxSens = ahora + PERIODO_SENS_MS;
      proto::Sensores s;
      portENTER_CRITICAL(&muxSensores);
      s = sensoresPub;
      portEXIT_CRITICAL(&muxSensores);
      enviarPorEnlaceActivo(trama, proto::empaquetarSensores(s, trama));
    }

    vTaskDelay(pdMS_TO_TICKS(5));
  }
}
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
void loop() { vTaskDelay(pdMS_TO_TICKS(1000)); }

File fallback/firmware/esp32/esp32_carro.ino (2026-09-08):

// ===========================================================================
// esp32_carro.ino — Controlador de hardware del carro WRO Future Engineers.
//
// El ESP32 ya NO tiene WiFi ni pagina web: es un controlador de hardware puro
// que obedece tramas binarias por serial. Toda la inteligencia (camara,
// navegacion, interfaz) vive en la Raspberry Pi. Motivos:
//   - una sola fuente de ordenes = no hay que arbitrar quien manda;
//   - ~40 KB de RAM y el nucleo 0 libres para atender el serial sin jitter;
//   - si la Pi se cuelga, el ESP32 para el carro solo (failsafe), que es
//     justamente la razon de tenerlo en medio.
//
// ENLACE: escucha las DOS bocas a la vez y contesta por la que recibio la
// ultima trama valida, asi el mismo binario sirve tanto si conectas por USB
// como si conectas TX/RX a los GPIO. No hay que recompilar para cambiar.
//   - Serial  (USB / UART0)
//   - Serial2 (GPIO16 = RX2, GPIO17 = TX2)  <- a GPIO14/15 de la Pi, cruzados
//
// PATAS INT (opcionales; sin ellas todo sigue funcionando por sondeo)
//   TCS34725 INT -> GPIO 19   borde de linea por hardware, enganchado
//   MPU6050  INT -> GPIO 18   data ready: dt exacto para integrar el yaw
//
// PULSADOR Y LED DE ESTADO (ver botones.h)
//   BOTON -> GPIO 13 a GND   arma y desarma (el mismo, como un cronometro).
//                            Pulsarlo con el carro ARMADO corta la traccion
//                            AQUI, en el tick siguiente, sin esperar a la Pi.
//   LED   -> GPIO 2          el azul de a bordo. Fijo = armado; un destello =
//                            listo; parpadeo rapido = sin ordenes de la Pi;
//                            dos destellos = cortado por el boton.
//
// TAREAS FreeRTOS
//   nucleo 0: tareaRx (prio 5)        lee UARTs, valida CRC, publica el mando
//             tareaSensores (3)       MPU6050 (yaw) + TCS34725 (lineas) por I2C,
//                                     despertada por las INT (latido de 5 ms)
//             tareaTelemetria (2)     estado a 20 Hz + sensores a 40 Hz
//   nucleo 1: tareaControl (4)        tick de 10 ms: rampas y escritura al HW
//             tareaVigilante (6)      si el control o la Pi se callan, corta
//
// SEGURIDAD: ver seguridad.h. Los topes del servo son constantes de
// compilacion y se aplican tres veces (al convertir, al rampar y al escribir).
// ===========================================================================

#include <Arduino.h>
#include <Wire.h>
#include "protocolo.h"
#include "seguridad.h"
#include "sensores_i2c.h"
#include "lineas.h"
#include "botones.h"

// ======================= PINES =======================
// Puente H (tal cual tu montaje actual)
const int PIN_RPWM = 25;
const int PIN_LPWM = 26;
const int PIN_R_EN = 27;
const int PIN_L_EN = 33;

// Servo de direccion (MG996R)
const int PIN_SERVO = 32;

// I2C compartido: MPU6050 (0x68/0x69) + TCS34725 (0x29)
const int PIN_SDA = 21;
const int PIN_SCL = 22;
const uint32_t I2C_HZ = 400000;

// Patas INT de los sensores. Las dos son OPCIONALES: si no estan cableadas,
// el firmware lo detecta solo y sigue por sondeo (mas lento y con mas jitter,
// pero funciona). Ver sensores_i2c.h para que aporta cada una.
//   TCS34725 INT -> GPIO 19   open-drain, activo BAJO  (pull-up interno)
//   MPU6050  INT -> GPIO 18   push-pull,  activo ALTO
const int PIN_INT_TCS = 19;
const int PIN_INT_MPU = 18;

// UART hacia la Raspberry
const int PIN_RX2 = 16;   // <- TX de la Pi (GPIO14)
const int PIN_TX2 = 17;   // -> RX de la Pi (GPIO15)
const uint32_t BAUDIOS = 115200;

// Pulsador de competencia, entre el pin y GND (pull-up interno). El 13 no es
// pin de arranque (strapping) ni de entrada-sola: pisado al encender no
// impide el boot ni deja el pin al aire.
const int PIN_BOTON = 13;
// LED de estado: el AZUL de a bordo, que en casi todas las placas ESP32 es el
// GPIO2. Si tu placa lo tiene en otro pin, cambialo aqui y ya. En competencia
// no hay web: este LED es lo unico que dice que esta pasando (patrones en
// botones.h).
const int PIN_LED_ESTADO = 2;

// Si el carro avanza al reves, cambia esto a 1 en vez de recablear.
#define INVERTIR_MOTOR 0

// ======================= PWM =======================
const int MOTOR_PWM_FREQ = 20000;   // 20 kHz: fuera del rango audible
const int MOTOR_PWM_RES  = 8;       // 0-255

const int SERVO_PWM_FREQ = 50;
const int SERVO_PWM_RES  = 16;
const int SERVO_PULSO_MIN_US = 500;
const int SERVO_PULSO_MAX_US = 2400;

// ======================= TIEMPOS =======================
const uint32_t TICK_CONTROL_MS  = 10;   // 100 Hz
const uint32_t PERIODO_TELE_MS  = 50;   // 20 Hz (estado del motor/servo)
const uint32_t PERIODO_SENS_MS  = 25;   // 40 Hz (yaw + color, si hay sensores)
const uint32_t FAILSAFE_MS      = 300;  // silencio tolerado de la Pi
const uint32_t VIGILANTE_MS     = 200;  // silencio tolerado del propio control
const uint32_t REINTENTO_I2C_MS = 3000; // sondear sensores que falten

const uint8_t VERSION_FIRMWARE = 4;   // 4 = trama de sensores con botones

// ======================= ESTADO COMPARTIDO =======================
QueueHandle_t colaMando = NULL;         // longitud 1, el nuevo pisa al viejo

volatile uint32_t msUltimoMando   = 0;
volatile uint32_t msUltimoControl = 0;
volatile uint8_t  ultimaSeq       = 0;
volatile uint8_t  estadoBits      = 0;
volatile uint8_t  pwmActual       = 0;
volatile uint8_t  anguloActual    = 100;
volatile uint32_t tramasMalas     = 0;
volatile int8_t   enlaceActivo    = -1;  // 0 = USB, 1 = GPIO, -1 = ninguno aun

seg::ControlServo servo;
seg::ControlMotor motor;

// El pulsador. Lo lee tareaControl (100 Hz, nucleo 1) y su estado se publica
// aqui para que la trama de sensores lo mande a la Pi.
bot::Panel boton;
volatile uint8_t bitsBotones = 0;      // bits proto::B_*

// --- sensores I2C (los toca solo tareaSensores; la copia publicada se
//     protege con un spinlock porque telemetria la lee desde otro nucleo) ---
sens::Mpu6050 mpu;
sens::Tcs34725 tcs;
lin::Clasificador clasificador;
proto::Sensores sensoresPub = {0, 0, 0, 0, 0, 0, 0, 0, 0};
portMUX_TYPE muxSensores = portMUX_INITIALIZER_UNLOCKED;

volatile uint8_t calPendiente = 0;       // proto::CAL_* pedido por la Pi
volatile bool cfgTcsPendiente = false;
proto::CfgTcs cfgTcsNueva;
// Umbral de la INT del TCS, en % del nivel de claro del piso (que el firmware
// aprende solo). Al ser relativo, no se estropea si cambia la integracion.
uint8_t pctUmbralInt = 55;

// --- interrupciones de los sensores -----------------------------------
// Los ISR no tocan el I2C (Wire no es seguro dentro de una interrupcion):
// solo apuntan CUANDO paso y despiertan a tareaSensores, que es la que lee.
TaskHandle_t hSensores = NULL;
static const uint32_t AVISO_MPU = (1u << 0);
static const uint32_t AVISO_TCS = (1u << 1);
volatile uint32_t usIntMpu = 0;          // micros() del ultimo DATA READY
volatile uint32_t usIntTcs = 0;          // micros() del ultimo borde de linea
volatile uint32_t nIntMpu = 0, nIntTcs = 0;
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

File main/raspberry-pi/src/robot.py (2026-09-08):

"""
robot.py — El nucleo: camara -> vision -> muro -> navegacion -> ESP32.

Un solo objeto Robot; la web lee su estado y le manda ordenes. El hilo de
control captura, procesa y decide; el enlace manda a 50 Hz en su propio hilo.
Si este hilo se atasca >250 ms, el enlace manda ceros; si el serial se calla
>300 ms, el ESP32 corta solo. El robot NACE DESARMADO: hay que pulsar ARMAR.

Al ARMAR en modo auto arranca la carrera (cronometro + conteo de esquinas).
En competencia el ARMAR de la web no vale (no hay teclado ni pantalla): manda
UN SOLO pulsador, que arma y desarma segun como este el carro. Cuelga del
ESP32 y llega en la trama de sensores; botones.py decide si fue pulsacion
corta o larga y entra por los mismos metodos que usa la web.
"""

from __future__ import annotations

import copy
import json
import threading
import time
from typing import Any, Dict, List, Optional

import cv2
import numpy as np

from . import botones as botones_mod
from . import camara as cam_mod
from . import color_config as cc
from . import dibujo, muro, params as params_mod, vision
from . import protocolo as P
from .carrera import Carrera, LISTO, TERMINADO
from .enlace import Enlace
from .geometria import Geometria
from . import lineas as lineas_mod
from .lineas import GestorLineas
from . import navegacion as nav
from .navegacion import Decision, Navegador
from .obstaculos import Esquivador


class Robot:
    def __init__(self, datos_params: Dict[str, Any], datos_colores: Dict[str, Any],
                 simulado: bool = False, fuente_imagen: Optional[str] = None):
        self.datos_params = datos_params
        self.datos_colores = datos_colores
        self.p: Dict[str, Dict[str, Any]] = params_mod.obtener(datos_params)["valores"]
        self.perfil_color = cc.obtener(datos_colores)
        self.simulado = simulado
        self.fuente_imagen = fuente_imagen

        self.geo = Geometria(self.p["geometria"])
        self.vision = vision.Vision(self.perfil_color["colores"])
        ### el modo de esquina por color lo comparten el gestor de lineas (que
        ### cuenta) y el navegador (que gira): mismo dict, un solo interruptor
        self.lineas = GestorLineas(self.p["lineas"],
                                   cfg_color=self.p["esquina_color"])
        self.carrera = Carrera(self.p["carrera"], self.lineas)
        self.navegador = Navegador(self.p["navegacion"], self.p["limites"],
                                   self.p["escape"], self.p["giro2t"],
                                   al_completar_giro=self._giro_completado,
                                   cfg_obst=self.p["obstaculos"],
                                   cfg_color=self.p["esquina_color"])
        self.esquivador = Esquivador(self.p["obstaculos"])
        self.enlace = Enlace(self.p["enlace"], simulado=simulado, al_log=self.log)
        # El pulsador de competencia. Cuelga del ESP32 y llega por la trama de
        # sensores, por eso el gestor lee del enlace. Se construye SIEMPRE,
        # tambien en --simulado: las pulsaciones virtuales de la web
        # (/api/cmd?boton=corta) entran por el mismo camino, asi que la
        # secuencia de start se ensaya en el PC igual que en la pista.
        self.botones = botones_mod.GestorBotones(
            self.p["botones"], self.enlace,
            acciones={"corta": self.boton_pulsado,
                      "larga": self.boton_largo},
            al_log=self.log)

        self.armado = False
        # Linea de calibracion en uso ("open" | "obstaculos" | "estacionar").
        # Solo decide en que lista se guardan y se buscan los perfiles.
        self.categoria = params_mod.categoria_de(
            datos_params, params_mod.obtener(datos_params)["nombre"])
        self.modo = "auto"                  # "auto" | "manual" | "parado"
        self.manual = {"vel": 0, "dir": 0, "t": 0.0}

        self.frame_crudo: Optional[np.ndarray] = None
        self.hsv: Optional[np.ndarray] = None
        self.frame_anotado: Optional[np.ndarray] = None
        self.masks: Dict[str, np.ndarray] = {}
        self.perfil: Optional[muro.PerfilMuro] = None
        self.decision = Decision()
        self.fps = 0.0
        self.error_camara = ""
        self.registro: List[str] = []
        self.t_linea_reciente = 0.0

        self._cap = None
        self._hilo: Optional[threading.Thread] = None
        self._parar = threading.Event()
        self._lock = threading.Lock()
        self._imagen_fija: Optional[np.ndarray] = None
        self._cfg_esp_firma = ""
        self._t_cfg_esp = 0.0
        self._cal_giro_hecha = False

    # -- registro ---------------------------------------------------------
    def log(self, txt: str) -> None:
        linea = f"{time.strftime('%H:%M:%S')} {txt}"
        print(linea)
        self.registro.append(linea)
        if len(self.registro) > 300:
            del self.registro[:150]

    # -- arranque ---------------------------------------------------------
    def iniciar(self) -> None:
        if self.fuente_imagen:
            img = cv2.imread(self.fuente_imagen)
            if img is None:
                raise SystemExit(f"No se pudo leer {self.fuente_imagen}")
            self._imagen_fija = img
            self.log(f"[robot] usando imagen fija {self.fuente_imagen}")
        else:
            self._abrir_camara()

        self.enlace.fijar_vmax(int(self.p["limites"]["vmax"]))
        self.enlace.iniciar()

        self._parar.clear()
        self._hilo = threading.Thread(target=self._bucle, daemon=True, name="control")
        self._hilo.start()
        self.botones.iniciar()

    def _abrir_camara(self) -> None:
        c = self.p["camara"]
        self._cap = cam_mod.abrir(indice=c["indice"], ancho=c["ancho"],
                                  alto=c["alto"], fps=c["fps"], fourcc="MJPG")
        if self._cap is None:
            self.error_camara = "no se pudo abrir la camara"
            self.log("[robot] " + self.error_camara)
        else:
            self.error_camara = ""
            self.aplicar_camara()
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

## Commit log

2026-06-02 refactor(vision): implement modular structure and add distance test
    - Reorganized the computer vision codebase into a modular architecture to ease future updates and scaling.
    - Maintained and isolated the current working functionality for color detection.
    - Added a new test script to calculate and calibrate estimated distances to the targets.
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2026-08-29 Arreglo de navegación, implementación de esquivar obstaculos, reconcetar a sensores MPU TCS
    [esp32_carro.ino, navegacion.py, obstaculos.py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]
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2026-08-31 Calibraciòn de color y parametros de obstaculos
    [run_20260829_144250.csv, run_20260829_144904.csv, run_20260829_144916.csv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]
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2026-09-02 limite de esquina y obstaculos, tambien se recalibró el azul para el tcs
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2026-09-07 Correción de giro, correción de sentido de esquivar obstaculos, correción para evitar girar completo al cruza un obstaculo
2026-09-07 piloto: modo de esquina por color (esquina_color)
    El TCS solo hace dos cosas: la primera linea fija el sentido y cada linea
    de ese color dispara un giro hacia adentro y cuenta una esquina; el otro
    color se ignora. El giro (GIRO_COLOR) lleva velocidad variable con el
    pasillo, se suelta en el acto al ver un pilar (manda el esquive, que no
    se toca) y se retoma cuando el pilar deja de mandar. Refractario propio
    para la misma linea pisada varias veces. Carrera espera a salir de la
    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
2026-09-07 piloto: re-anclar el rumbo a la recta real y frenar ante linea vista
    Giro al lado incorrecto visto en pista: si el TCS se pierde la linea y el
    centrado toma la curva solo, la recta de referencia se queda una esquina
    atras y el yaw tira al 45 % hacia ella (= al lado contrario) hasta la
    pared; en la linea siguiente el objetivo salia 90 grados desfasado. Ahora
    (navegacion.reanclar_rumbo) en recta se adopta la recta nueva si el carro
    lleva reanclar_ms girado ~90 en el sentido de la ronda, y al apuntar una
    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
2026-09-08 Reestructura del repo y documentacion de ingenieria para la WRO
    Estructura nueva, pensada para que un juez encuentre cada cosa:
    open-challenge/ programa completo del reto abierto (Pi + ESP32)
    obstacle-challenge/ programa completo del reto de obstaculos
    schemes/ diagrama de bloques, cableado, pinout y presupuesto electrico
    3d-model/ piezas impresas (STL) y proyectos laminados
    images/ equipo, vehiculo, construccion y capturas reales de pista
    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
    [Arriba.stl, Component2.stl, Component3.stl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]
2026-09-08 boton unico de armar/desarmar y LED de estado en el ESP32
    El pulsador pasa del GPIO de la Pi al ESP32 (GPIO13) y viaja como nivel en la trama de sensores; la misma pulsacion arma y desarma. Con el carro armado una pulsacion solo puede querer decir parar, as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
2026-09-08 Carpetas por rama: main/ y nuevaspruebas/
    Cada codigo queda en la carpeta que lleva el nombre de la rama de la que
    viene, para poder cambiar de ejecutable cuando haga falta:
    main/ codigo de la rama main (sistema reconizer)
    nuevaspruebas/ codigo de la rama nuevas_pruebas (piloto)
    Ambas con la misma forma por dentro: raspberry-pi/ y firmware/esp32/.
    - open-challenge/ pasa a nuevaspruebas/ y obstacle-challenge/ se elimina:
    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
2026-09-10 Rename code folders to main/ + fallback/ and update the README
    Promote the raced system to main/ and demote the previous one:
    - nuevaspruebas/ -> main/ (the car we race)
    - main/ -> fallback/ (reconizer, the system before it)
    Cross-references updated in README.md, main/README.md, fallback/README.md,
    images/, journal/, schemes/pinout.md and schemes/wiring-diagram.svg.
    README changes:
    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
2026-09-10 Corregir el nombre del tutor y agregar los videos de las dos rondas
    - Msc. Edgardo Paolini (estaba escrito "Egardo")
    - Open Challenge y Obstacle Challenge enlazados en video/video.md y en la
    tabla de cumplimiento de reglas del README
2026-09-11 correción de dirección de archivo
    [Camera Support Mount 82.5g.3mf, CameraMount_82.5g.3mf, Crown Gear 48D Train Type.3mf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]
2026-09-11 corrección de objetos faltantes y organización por grupo
    [Camera Support Mount 82.5g.3mf, CameraMount_82.5g.3mf, Crown Gear 48D Train Type.3mf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]
2026-09-11 Sistema de control para el reto de obstaculos
    Pila autocontenida en obstaculos/: firmware ESP32 (FreeRTOS, failsafe, MPU-6050 y TCS34725 a registro) y piloto en la Raspberry Pi 5 (vision, FSM, enlace serial a 50 Hz). Sin logica de estacionamiento.
    [camara.py, carril.py, config.py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]
2026-09-11 Que la altura mande sobre la base, y que el carro no se frene solo
    Un mastil torcido borraba todos los pilares: el filtro exigia que la distancia por base y por altura coincidieran, y la base depende de la inclinacion. Ahora la altura es la medida primaria. Ademas: 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
2026-09-11 Un hueco tiene direccion, no posicion
    El rumbo hacia la salida se calculaba como un lateral en mm sobre una fila inventada: daba 7 % de volante con la curva abierta de par en par. Ademas argmax sobre la meseta de sectores libres elegia s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
2026-09-11 Mantener el rumbo no es mantener el volante
    El compromiso congelaba el angulo de volante del ultimo frame con pilar a la vista, y un volante fijo traza un arco: 537 mm de desvio en 0.8 s hacia el lado por el que acababa de esquivar. Ahora se s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
2026-09-11 La esquina la dice el piso, no la camara
    El giro raro seguia despues del arreglo anterior porque las curvas seguian siendo cosa de la vision. La camara solo sabe decir que el frente se cerro, y eso le pasa en una esquina igual que cuando el carro quedo apuntando a un muro tras rebasar: giraba antes de tiempo (ve el muro un metro antes de que empiece la curva, o sea recorta) y giraba a medias (el seguidor de carril renegocia el volante cada ciclo contra el centrado, y en cuanto asoma hueco afloja).
    Ahora la linea del piso dice CUANDO, la camara confirma QUE ESTA AHI (el frente tiene que estar cerrado) y el sentido de la ronda dice HACIA DONDE. Entre esquina y esquina el carro va recto. Estad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
    [carril.py, config.py, fsm.py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]
2026-09-11 El sensor de color preguntaba siempre un pelo antes de tiempo
    No detectaba bien las lineas del piso, y no era el sensor ni los umbrales: era aritmetica. El chip integra periodoMs y el firmware preguntaba cada periodoMs. Dos relojes libres a la misma frecuencia derivan, la pregunta cae siempre justo antes de que el dato exista, y como el hueco siguiente ya estaba reservado el periodo real se DOBLA. Una linea de 20 mm a 1 m/s dura 20 ms: en un hueco de 48 ms cabe entera sin dejar rastro. Es el mismo fallo que ya se midio y arreglo en main.
    Cuatro arreglos, y los tres ultimos salieron al medir el primero: sondear cada 2 ms y coger la muestra cuando AVALID lo dice, con atime 24 ms a 12 ms (gana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
    [config.py, esp32_obstaculos.ino, fsm.py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]
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
